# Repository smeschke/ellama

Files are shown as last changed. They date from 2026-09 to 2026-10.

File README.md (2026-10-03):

# eLlama

A four-wheel-drive outdoor robot base, walking-speed, that you drive with a handheld controller and that doubles as a mount for teleoperated or autonomous compute. You bring the battery and, if you want one, the computer.

Demo video: **[youtu.be/O5k8u-hmhis](https://youtu.be/O5k8u-hmhis)**. Try the 3D drive simulator without installing anything, hosted on Hugging Face Spaces: **[huggingface.co/spaces/r5d2/ellama-simulator](https://huggingface.co/spaces/r5d2/ellama-simulator)**.

## Who it's for

People who know they will want a capable outdoor robot in three to five years, and want something to iterate on now, before they buy the real one. Software, sensing, and autonomy ideas get tested on a robot that is cheap, repairable, and driven outdoors for real, so the ideas are proven by the time the commercial platform is worth buying.

The design leans on that. eLlama supplies only the slow-moving parts (motors, gearboxes, wheels, plywood, an ESP32, and a radio protocol) and leaves the fast-moving part, the computer, camera, and model, to the owner, in a box sized to take whatever comes next. The reasoning is in [`context-pack/01-overview.md`](context-pack/01-overview.md).

## Specs

| | |
| --- | --- |
| Drive | 4 x RS550 brushed motors, 100:1 gearboxes, 10 in pneumatic wheels |
| Power | Bring your own battery: 12 V 7 Ah SLA, 18 V cordless-tool pack, or 12 V LiFePO4 (see [`context-pack/05-battery-options.md`](context-pack/05-battery-options.md); LiFePO4 not yet tested) |
| Motor drivers | 4 x BTS7960 |
| Control | ESP32 (Llama Motor Board), ESP-NOW handheld controller or USB serial bridge to a computer |
| Sensing | AS5600 wheel encoders, IMU (GY-521 / MPU-6050 / ICM-20948 sketches) |
| Charging | Off the robot, with your battery's own charger |
| Weight | About 32 lb without a battery, 37 lb with one 12 V SLA, 42 lb with two |

## How it works

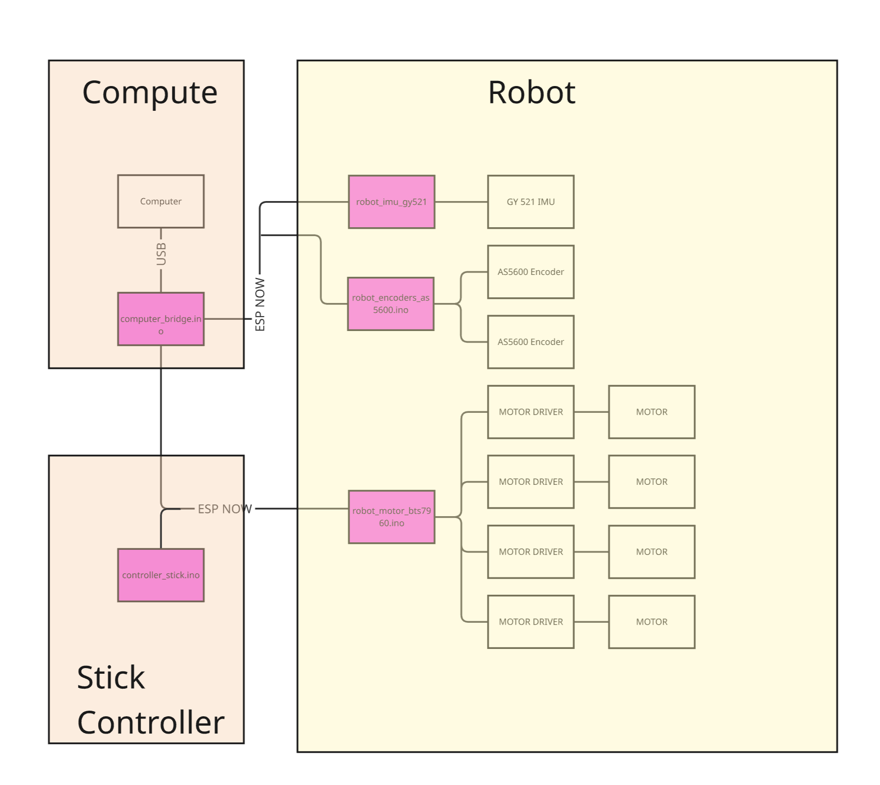
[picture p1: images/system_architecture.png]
System architecture


Drive the robot with the stick controller or with a computer through the USB bridge, one at a time, with no firmware changes. Both send the same drive packets over ESP-NOW to the motor board. The encoder and IMU boards broadcast telemetry that the bridge relays back to the computer.

## Status

**Works:** manual and remote driving, encoder and IMU telemetry, encoder-closed-loop moves ("go forward 10 inches") from Python or an AI agent through the MCP server, camera and lidar streaming over the network, and the calibrated simulators. Over 13 miles of field runs are logged in [`context-pack/Testing.csv`](context-pack/Testing.csv), failures included.

**Not there yet:** obstacle sensing, and an emergency stop beyond the power switch. Until obstacle sensors exist, anything commanding the robot must follow [`DRIVING_POLICY.md`](DRIVING_POLICY.md).

## Repo layout

| Path | What's there |
| --- | --- |
| [`context-pack/`](context-pack/) | Design docs and the [user manual](<context-pack/eLlama User Manual.md>) |
| [`firmware/`](firmware/) | ESP32 Arduino sketches (controller, motor board, bridge) |
| [`teleop/`](teleop/) | Python client/server scripts for driving, video, and lidar over the network |
| [`calibration/`](calibration/) | Sensor validation and calibration tools that read the computer bridge: live encoder/IMU view and calibration |
| [`mcp_server/`](mcp_server/) | MCP server so an AI agent can drive the robot by encoder feedback ("go forward 10 inches") instead of guessing a duration |
| [`simulation/`](simulation/) | Calibrated 2D/3D drive-command simulators and a CSV replay script |
| [`images/`](images/) | Photos and diagrams |

## License

Released under the [MIT License](LICENSE).

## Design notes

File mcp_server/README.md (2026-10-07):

# MCP server

An MCP server that lets an AI agent drive eLlama by encoder feedback instead of by
guessing a duration — "go forward 10 inches" becomes a tool call that watches the wheel
encoders and stops itself at the target, rather than a fixed-time open-loop command.

Talks over the same USB-serial link as `calibration/live_view.py`:
[`firmware/computer_bridge/computer_bridge.ino`](../firmware/computer_bridge/computer_bridge.ino)
on a spare ESP32, plugged into whatever machine runs this server. Reuses
[`calibration/bridge.py`](../calibration/bridge.py) for serial I/O, line parsing, and the
distance/heading math — one place that logic lives, not two.

**Read [`../DRIVING_POLICY.md`](../DRIVING_POLICY.md) before using this.** The short
version, enforced in code by `robot_server.py`: every tool that can move the robot
requires `confirmed_safe=true`, which must only be set after asking the human operator
about that specific move, in the moment. This server has no obstacle sensors — only
wheel encoders and an IMU — so there is no way for it to verify the area is clear on its
own. If real proximity/vision sensing ever gets wired into this server, a sensor-verified
small bump could skip the ask; until then, ask every time, regardless of move size.
First-time-testing-a-new-motor and full-power moves require asking even after that.

## Setup

```
python3 -m venv --system-site-packages mcp_server/.venv
mcp_server/.venv/bin/pip install mcp
```

(`--system-site-packages` so it reuses the `pyserial` already installed for
`calibration/`, instead of a second copy.)

Plug in the bridge ESP32 (flashed with `computer_bridge.ino`) — usually `/dev/ttyUSB0`.
`robot_encoders_as5600` and a `robot_imu_*` sketch need to be running on the robot itself
for telemetry to flow; without them, every drive tool refuses to move (see "no live
encoder telemetry" below).

Register with an MCP client via `.mcp.json` (already set up at the repo root) or run
directly to sanity-check it starts:

```
mcp_server/.venv/bin/python mcp_server/robot_server.py
```

## Tools

| Tool | Moves the robot? | Needs `confirmed_safe`? |
| --- | --- | --- |
| `read_telemetry()` | No | — |
| `look(width=640)` | No | — |
| `zero_odometry()` | No | — |
| `stop()` | Commands zero PWM (active braking) | No — always safe |
| `listen()` | Stops and releases control to the stick controller | No — always safe |
| `connect(port=None)` | No | — |
| `start_recording(name=None, auto_photo=False)` | No | No |
| `add_marker(text)` | No | No |
| `take_photo(note="")` | No | No |
| `stop_recording()` | No | No |
| `drive_distance(distance_inches, direction, pwm, confirmed_safe)` | Yes | Yes |
| `turn_degrees(degrees, direction, pwm, confirmed_safe)` | Yes | Yes |
| `drive_arc(radius_inches, degrees, direction, pwm, confirmed_safe, max_wheel_pwm=125, travel="forward")` | Yes (curved; 360° = full circle; `travel="reverse"` backs up along the arc) | Yes |
| `jog(left_pwm, right_pwm, duration_s, confirmed_safe, require_telemetry=True)` | Yes (raw, time-based) | Yes |
| `line_view(width=640)` | No | — |
| `person_view()` | No | — (finds people in the live frame, returns bearing to each) |
| `turn_to_me(confirmed_safe, max_seconds=30, name=None, spin_speed_dps=18, lost_timeout_s=1)` | Yes (spins in place, holds until it ends; max_seconds / lost_timeout_s of 0 = never) | Yes — once per run; refuses to start if 0 or >1 people are in view (ask the operator) |
| `turn_to_me_set(max_seconds, lost_timeout_s, spin_speed_dps)` | No (adjusts an already-approved run) | — |
| `turn_to_me_status(wait_s=0)` | No | — |
| `start_line_follow(confirmed_safe, speed_pwm=58, max_seconds=90, name=None, show_on_phone=False)` | Yes (autonomous, until it ends) | Yes — once per run (`show_on_phone` also shows the overlay + motor panel on the phone; see `phone/README.md`) |
| `line_follow_status(wait_s=0)` | No | — |
| `lights(on=True, brightness, color, effect, speed, intensity)` | No (WLED strip at `ELLAMA_WLED_HOST`, default 192.168.0.57) | — |
| `list_light_effects()` | No | — |
| `lights_blink(blinks=2, phase_s=0.3, color="00ff00", brightness=127, restore=True, fade=True)` | No (on off on off on = 1.5 s by default, each phase fading) | — |
| `speak(text, speed=1.3, max_brightness=127)` | No (Piper TTS out of this computer's speakers, WLED strip animates a mouth; blocks until done. Env: `ELLAMA_PIPER`, `ELLAMA_PIPER_VOICE`) | — |

`look()` returns a photo from the phone camera on the robot (Android "IP Camera" or "IP
Webcam" app). The phone is found by scanning the local /24 for ports 8080/4444, or set
`ELLAMA_CAM_URL` (e.g. `https://192.168.0.54:4444`) to skip the scan. A snapshot takes
~5-8s. It is advisory vision only and does not replace `confirmed_safe`.

## Recording a stick-driven run

The server can log telemetry while you drive with the stick: it only transmits when a drive
tool is called, so the bridge stays listen-only. Ask the agent to `start_recording`, drive,
ask for markers and photos as you go, then `stop_recording`. Everything lands in
`recordings/<name>/`:

- `<name>.csv` — same columns as `calibration/live_view.py --csv` plus a trailing `note`
  column, so `python3 calibration/analyze_csv.py recordings/<name>/<name>.csv` works. Rows
  are `ENC` / `IMU` samples, plus `MARK` (from `add_marker`) and `PHOTO` (from `take_photo`)
  rows that carry the state at that moment and the text or photo filename in `note`.
- `photo_001.jpg`, ... — full-size phone-camera snapshots. The `PHOTO` row is stamped when the
  photo is requested; the snapshot itself arrives ~5-8 s later.

`start_recording(auto_photo=True)` photographs the robot by itself whenever it comes to rest
(wheels still ~0.7 s) after moving at least ~4 in of wheel travel or ~10° of yaw since the
last photo, plus one at the start. The `PHOTO` row is stamped when the robot stopped. The
snapshot takes ~5-8 s, so if the robot moves again before it arrives, a `MARK` row notes
"robot moved during capture" and that photo shouldn't be trusted for pose. Thresholds are
the `AUTO_PHOTO_*` constants in `robot_server.py`.

Only one program can hold the bridge's serial port, so `live_view.py` can't run at the same
time. Only one ESP32 may transmit drive commands at a time: keep the stick controller on for
this (nothing is sent to the robot) and don't call a drive tool while it drives.

`drive_distance` and `turn_degrees` are closed-loop: they stop themselves once the
target is confirmed reached, or after a generous timeout, whichever comes first.
`drive_distance` uses the wheel encoders; `turn_degrees` uses the IMU's gyro-integrated
yaw (see "Known unknowns" below for why). Both refuse to run without live telemetry from
the sensor they depend on, always stop-and-settle before starting (so a direction
reversal is never commanded without a stop in between), and cap how far a single call
can go (`MAX_SINGLE_MOVE_IN` / `MAX_SINGLE_TURN_DEG` in `robot_server.py`) — chain
further confirmed calls for more, checking `read_telemetry()` between them, per
`DRIVING_POLICY.md`'s stop-check-decide-move loop. `jog` is the odd one out: open-loop,
raw PWM, fixed duration, no target — for bench/commissioning tests, capped at
`MAX_JOG_DURATION_S`.

`drive_distance`, `turn_degrees`, `drive_arc` and `jog` take `warn_lights=True`: right before the motors start the WLED strip does the 1.5 s fading `lights_blink` pattern (on off on off on, then solid green at 50% while moving) and is restored when the move ends. Pass `warn_lights=False` to skip it. A strip that can't be reached never blocks a move.

## Known unknowns

- **Direction sign: verified 2026-09-27.** Robot on blocks, wheels free to spin,
  `drive_distance(distance_inches=12, direction="forward", pwm=50, ...)` — all four
  wheels visibly spun backwards. `FORWARD_PWM_SIGN` is now `-1` to correct for this.
  Re-verify the same way after any change to wiring, motor board firmware, or which
  physical wheel is "left" vs "right".
- **Wheel encoders overestimate in-place turns by ~2x — verified 2026-09-27.** Robot on
  the ground, four 90° turns left then four right, pwm=60: the encoder-differential
  estimate (`dr - dl` over `track_width_in`) reported ~92° per commanded 90° turn, but
  the robot visually rotated only ~47° each time (confirmed by eye) — wheel scrub during
  an in-place spin turns the wheels much more than the chassis actually rotates. The
  IMU's gyro-integrated yaw over those same turns averaged ~49° per turn, matching the
  ~47° observed. `turn_degrees` now uses IMU yaw as its stop condition and ground truth;
  the encoder number is still returned as `encoder_degrees_estimate`, explicitly labeled
  unreliable. This means `track_width_in` miscalibration was never the real problem for
  turns specifically (it may still matter for other uses of encoder heading, e.g.
  `calibration/live_view.py`'s own dead-reckoning, which doesn't have an IMU fallback).
  IMU yaw drift over a multi-minute session is a separate, smaller concern this hasn't
  characterized yet — fine for single turns a few seconds long, unverified for anything
  longer.
- **Gear ratio is overridden in memory, not in the file.** `calibration/config.json`
  still says `gear_ratio: 6.33`; `calibration/analyze_run.py` found the true ratio is
  `4.5` (confirmed by `calibration/30_inches.csv`, a real tape-measured run). This server
  uses `4.5` regardless of what the file says — `TRUE_GEAR_RATIO` in `robot_server.py` —
  left that way deliberately so it could be tested independently before touching the file.

## Safety net beyond the confirmation gate

- `firmware/computer_bridge/computer_bridge.ino` now falls back to listen-only if no
  serial line arrives for 500ms while transmitting, so a crashed/killed server process
  doesn't leave the robot driving forever.
- The server itself sends `stop` on normal exit, `SIGINT`/`SIGTERM`, and at the end of
  every `drive_distance`/`turn_degrees` call (`try`/`finally`), whether or not the target
  was reached.
- Neither of those is a substitute for the confirmation gate — they bound how long a
  *stuck* command runs, not whether a command should have been sent at all.

## Line following

`start_line_follow` runs a camera -> detect -> steer loop on its own thread (`line_vision.py`
finds the 3/4in tape, `line_follow.py` turns it into wheel commands, `camera_stream.py` shares
the phone's `/video/mjpeg` stream). One `confirmed_safe` covers the run. It stops by itself and
reports why: `finish_candidate` (something like the end strip; may be paint or glare), `end_of_tape` (line
vanished right after a cross strip), `lost` (no line for 0.5 s), `stale` (no camera
frame), `telemetry_stale`, `timeout`, or `stopped` (`stop()` / `listen()` abort it at any time). These are claims for the AI to check with
`line_follow_report`, not verdicts. It never searches for a lost line. Other drive tools refuse while it runs. The run is recorded
to `recordings/<name>/` (telemetry CSV, `video.mp4`, `video_times.csv`, `follow_log.csv`).
`line_follow_sim.py` is a closed-loop sanity check of the controller, not a prediction -- its
constants are fit from `tape_manual_run1/2` and need tuning on the real robot.

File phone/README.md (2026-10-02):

# Phone display and benchmarks

The robot's Android phone runs Termux (F-Droid build) with Python, so the computer can put
live pictures on its screen and run small experiments there.

## One-time setup on the phone (Termux)
`pkg install python openssh python-numpy python-pillow tur-repo python-onnxruntime termux-api`,
install the **Termux:API** Android app too, and authorize the computer's SSH key
(`~/.ssh/ellama_phone_ed25519.pub` -> `~/.ssh/authorized_keys` in Termux). Start `sshd`
(port 8022) after every Termux restart. The phone address is whatever the camera app shows
(was 192.168.0.54).

## Live display (used by `start_line_follow(show_on_phone=True)`)
1. Copy `display_server.py` and `show.html` to `~/ellama/` on the phone:
   `scp -i ~/.ssh/ellama_phone_ed25519 -P 8022 display_server.py show.html termux@<phone>:ellama/`
2. In Termux: `cd ~/ellama && python display_server.py &`  (serves port 8080; kill it with
   `pkill -f display_server` from a *separate* command, not from the same ssh command line).
3. On the phone: `termux-open-url http://127.0.0.1:8080/show.html` (or open that address in the
   browser). Opening the plain image file with `termux-open` fails ("unable to display shared
   content"); the browser page works.
4. From the computer: `phone/show.sh picture.jpg` shows any image; the MCP server posts live
   frames with a motor-command panel when a run is started with `show_on_phone=true`
   (mcp_server/phone_display.py). Override the address with `ELLAMA_PHONE_DISPLAY`.

The display server has no login: anyone on the Wi-Fi can replace the picture. It only ever
writes `show.jpg`.

## Detector benchmark
`bench.py` runs the pose model (ONNX, numpy + onnxruntime + Pillow only) on an image and
times it: ~97 ms/frame at 320x192 with 6 threads on the A13-class phone (~230 ms at 480x288).
Models live in `models/` (gitignored; re-export from yolo11n-pose with imgsz=[320,192]).
This phone has **no gyroscope or magnetometer** (accelerometer only), so yaw still comes from
the robot's own IMU.

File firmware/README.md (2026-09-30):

# Firmware ⚡

Arduino sketches for every ESP32 in the system — one for the controller, one for the robot's motor board, plus a bench test sender. All of it is plain Arduino with no libraries beyond `esp_now.h`. Everything talks ESP-NOW on channel 1, no encryption, packet type distinguished purely by length.

## Sketches

| Sketch | Flashes onto | Does |
|---|---|---|
| [`controller_stick/controller_stick.ino`](controller_stick/controller_stick.ino) | single stick controller | Reads the joystick, arcade-mixes it, streams `DrivePacket{left, right}` every 40 ms |
| [`robot_motor_bts7960/robot_motor_bts7960.ino`](robot_motor_bts7960/robot_motor_bts7960.ino) | Llama Motor Board | Ramps toward the commanded left/right PWM on four BTS7960 channels, with a 300 ms fail-safe stop |
| [`computer_bridge/computer_bridge.ino`](computer_bridge/computer_bridge.ino) | spare ESP32 on a bench/PC | Reads `<left> <right>` over serial and re-sends it as `DrivePacket` over ESP-NOW; also listens for `EncoderPacket`/`ImuPacket` telemetry and relays them to serial as `ENC <left> <right> <ms>` / `IMU <ax> <ay> <az> <gx> <gy> <gz> <ms>` — listen-only until it is sent a drive line (`listen` returns it to silent), so it can log alongside the stick controller — lets a computer drive the robot and capture wheel-encoder and IMU data directly |
| [`robot_encoders_as5600/robot_encoders_as5600.ino`](robot_encoders_as5600/robot_encoders_as5600.ino) | Llama Encoder Board (prototype on a breadboard) | Reads two AS5600 wheel encoders (one per I2C bus), broadcasts `EncoderPacket{left, right, ms}` (12 bytes) over ESP-NOW ~50x/sec |
| [`bench_motor_bts7960_test/bench_motor_bts7960_test.ino`](bench_motor_bts7960_test/bench_motor_bts7960_test.ino) | bench-test ESP32 wired to the BTS7960 drivers, USB-tethered | Runs one motor channel (`fl`/`bl`/`fr`/`br`) at a time from the Serial Monitor at a low, clamped PWM for a few seconds, with slow ramping and auto-stop — no ESP-NOW |
| [`bench_encoders_as5600_test/bench_encoders_as5600_test.ino`](bench_encoders_as5600_test/bench_encoders_as5600_test.ino) | bench-test ESP32, USB-tethered | Standalone dual-AS5600 sanity check (per-encoder magnet alignment, angle/RPM; left on GPIO 21/22, right on 18/19) with Serial-only output, no ESP-NOW |
| [`robot_imu_icm20945/robot_imu_icm20945.ino`](robot_imu_icm20945/robot_imu_icm20945.ino) | robot — IMU board | Reads a GY-ICM20945 V2 (bank-switched registers, WHO_AM_I 0xEA) over I2C, broadcasts the same 16-byte `ImuPacket{accel, gyro, ms}` over ESP-NOW ~50x/sec, gyro-bias-corrected at boot |
| [`robot_imu_mpu6050/robot_imu_mpu6050.ino`](robot_imu_mpu6050/robot_imu_mpu6050.ino) | robot — IMU board (temporary, bench-taped) | Reads a GY-521 (MPU6050) over I2C, broadcasts `ImuPacket{accel, gyro, ms}` over ESP-NOW ~50x/sec |
| [`robot_imu_gy521/robot_imu_gy521.ino`](robot_imu_gy521/robot_imu_gy521.ino) | robot — IMU board | Hardened GY-521 sender: auto-detects address 0x68/0x69, accepts clone WHO_AM_I values, enables the ~44 Hz DLPF, skips failed reads and re-inits on disconnect, retries bias calibration if moved. Same 16-byte `ImuPacket` — no bridge/PC changes |
| [`bench_imu_mpu6050_test/bench_imu_mpu6050_test.ino`](bench_imu_mpu6050_test/bench_imu_mpu6050_test.ino) | bench-test ESP32, USB-tethered | Standalone GY-521 sanity check (gyro bias calibration, pitch/roll/yaw) with Serial-only output, no ESP-NOW |
| [`bench_imu_icm20945_test/bench_imu_icm20945_test.ino`](bench_imu_icm20945_test/bench_imu_icm20945_test.ino) | bench-test ESP32, USB-tethered | Standalone GY-ICM20945 V2 sanity check (gyro bias calibration, pitch/roll/yaw) with Serial-only output, no ESP-NOW — the GY-521's replacement candidate |

## Setup

Standard ESP32 Arduino toolchain — install the ESP32 board package, pick your board, flash over USB. The controller flashes through the same USB-C port that powers it, no disassembly.

The single stick controller broadcasts, so it drives any `robot_motor_bts7960.ino` listening on the same WiFi channel — no MAC address configuration needed. `computer_bridge.ino` broadcasts the same way once it is sent a drive line, so it works when driving from a computer instead of the stick; until then it only listens, so it can log telemetry while you drive with the stick.

**Only one ESP32 should transmit drive commands at a time.** The motor board follows whichever `DrivePacket` arrives last, so two senders fight and neither works properly. Unplug the stick controller from its battery when driving from the computer bridge, and put the bridge in listen mode (send `listen`) or unplug it when driving with the stick.

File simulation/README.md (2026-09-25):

# Simulation

Path planning and dry-run simulators for eLlama's open-loop drive commands (`pwml pwmr time_ms`, the same three numbers the firmware's `DrivePacket{left, right}` and `computer_bridge.ino` expect). Two UIs, each with a "simple" and a "complex" version:

| Script | UI | Input |
| --- | --- | --- |
| [`simulator.py`](simulator.py) | OpenCV, top-down 2D | Free-text MDI box, one `pwml pwmr time_ms` line per command |
| [`simulator_complex.py`](simulator_complex.py) | OpenCV, top-down 2D | Editable MDI grid, plus click-to-add waypoints (turn-then-drive or arc mode) |
| [`simulator3d.html`](simulator3d.html) | Browser, 3D (three.js) | Same free-text MDI box as `simulator.py` |
| [`simulator3d_complex.html`](simulator3d_complex.html) | Browser, 3D (three.js) | Same grid + click-to-waypoint planning as `simulator_complex.py` |

Run a Python one with `python3 simulator_complex.py`; open an `.html` one directly in a browser, no server needed. You can also try the 3D simulator without installing anything, hosted on Hugging Face Spaces: **[huggingface.co/spaces/r5d2/ellama-simulator](https://huggingface.co/spaces/r5d2/ellama-simulator)**.

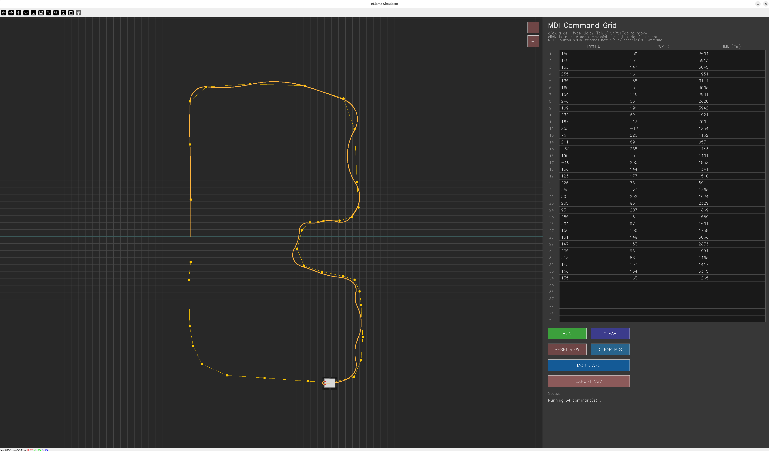
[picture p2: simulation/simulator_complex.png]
Top-down MDI grid simulator with a planned path

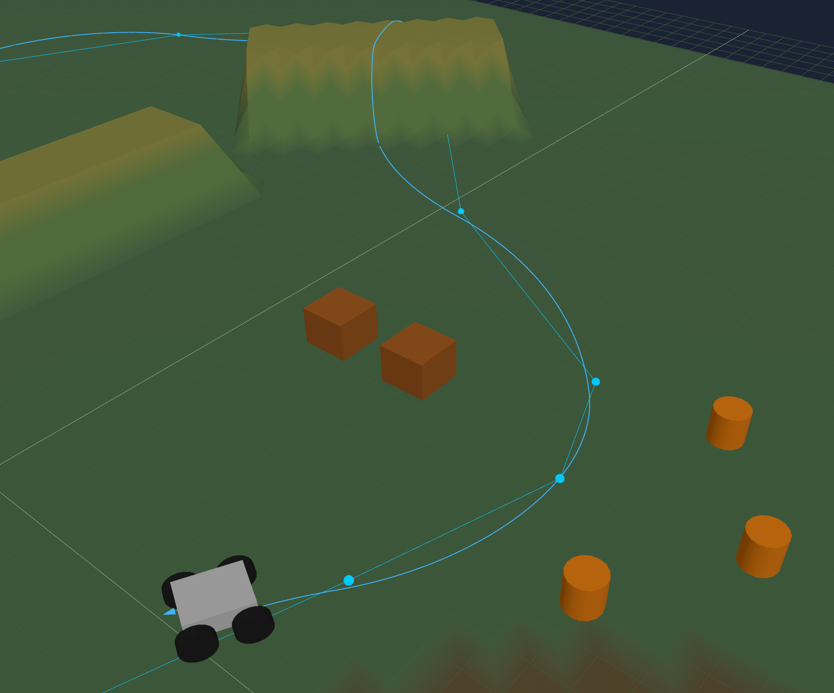
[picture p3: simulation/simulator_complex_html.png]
3D browser simulator with click-to-waypoint arc planning


## Why this is more than a toy

eLlama has no wheel encoders or other odometry feedback — commands are pure open-loop PWM + duration. To make the simulator worth trusting, I drove the real robot with simple commands (e.g. `120 -120 1800`), measured the actual distance/turn on the ground, and calibrated the simulator's speed and turn-rate model to match those measurements (see the `_SPEED_PTS` and `TURN_SCRUB_FACTOR` comments at the top of each script). The result: for a reasonable command like `150 150 2000`, the path drawn in the simulator tracks what the robot actually does closely enough to plan with.

Because there's no feedback, error still accumulates over a run, and it shows up most on turns (skid-steer scrubs unpredictably). Straight-line forward/back commands are the reliable case — under about 8 ft of travel, the robot usually lands within a fraction of an inch of the simulated endpoint. That's good enough to plan multi-step paths in the simulator, export them, and expect the real robot to follow along.

## Safety: MAX PWM is required, and there's no default on purpose

Every UI has a **MAX PWM** field. RUN and EXPORT CSV both refuse to act until it's set, and once it is, every command's `(pwml, pwmr)` pair is scaled down — preserving the ratio between them, so a turn's shape doesn't change, only its speed — so neither wheel exceeds it.

There's deliberately no baked-in default. The first version of this tool didn't have this control, and the click-to-waypoint arc planner (which picks whatever PWM gets to the clicked point at a steady speed) happily wrote out full-throttle 255 commands on tight turns — accurate to what the robot actually did, just much faster than expected the first time it ran unattended. That's a general risk, not specific to this planner: AI-assisted or auto-generated motion code tends to reach for whatever value produces the desired motion fastest, which in an unconstrained PWM range usually means near-maximum. **Start with the lowest PWM that's still effective for what you're testing, watch it run, and only raise the ceiling once you trust the path** — don't hand a fresh command list to the real robot at whatever PWM it happened to be written with.

Separately: PWM magnitudes much below ~40 tend not to produce any real motion at all — that's mechanical (motor/gearbox static friction), not a firmware-enforced deadband, so the simulator won't warn you about it. A command with `|pwm|` in the single or low double digits may look fine in the preview and simply do nothing on the real robot.

## Workflow

1. Build a path in the simulator — type commands directly, or click the ground to drop waypoints (complex versions plan the turn+drive or arc command for you).
2. Click **EXPORT CSV** (Python) or the export button (3D) to write `pwml,pwmr,time_ms` rows to `exported_path.csv`.
3. Replay it on the real robot with [`send_csv.py`](send_csv.py), which streams each row over serial to an ESP32 running `computer_bridge.ino` at the wire protocol described in [`firmware/README.md`](../firmware/README.md):

   ```
   python3 send_csv.py exported_path.csv --port /dev/ttyUSB0
   ```

   It always sends `stop` on exit, Ctrl+C, or error, since `computer_bridge.ino` repeats the last command forever until told otherwise.

## Robot model

Both simulators use the same kinematic model, built from the real chassis dimensions in [`images/chassis_dimensions_isometric.png`](../images/chassis_dimensions_isometric.png):

- Differential (skid-steer) drive: `v = (v_l + v_r) / 2`, `omega = (v_r - v_l) / effective_track_width`
- PWM → speed is piecewise-linear, calibrated from real straight-line runs
- Turning uses an inflated *effective* track width (`TURN_SCRUB_FACTOR`) to account for how much a 4-wheel skid-steer chassis scrubs sideways during a turn, calibrated from a real 90° pivot

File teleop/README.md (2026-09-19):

# Teleop

Python client/server pairs for driving eLlama, watching its camera, and viewing lidar sweeps over the network. Servers run on the robot's compute module (a Pi); clients run on your laptop.

## Scripts

| Script | Runs on | Does |
| --- | --- | --- |
| [`command_server.py`](command_server.py) | Pi | Receives drive commands (`FWD`, `REV`, `SPIN <nx>`, `STOP`) over TCP and forwards motion to the ESP-NOW sender over serial at 20 Hz |
| [`command_client.py`](command_client.py) | laptop | Connects to `command_server.py` and drives with the keyboard (w/s/a/d, up/down for speed, space to stop) |
| [`video_server.py`](video_server.py) | Pi | Captures the camera and streams JPEG frames over TCP |
| [`video_client.py`](video_client.py) | laptop | Connects to `video_server.py` and displays the live feed |
| [`lidar_server.py`](lidar_server.py) | Pi | Reads LD06 lidar packets over serial, accumulates one 360° sweep at a time, and streams each finished sweep over TCP |
| [`lidar_client.py`](lidar_client.py) | laptop | Connects to `lidar_server.py` and displays each completed sweep |

Each pair is independent — run whichever combination you need (e.g. `command_server.py` + `video_server.py` together for full teleop, or just the lidar pair on its own).

Servers listen on plain TCP with no encryption or auth, matching the firmware's ESP-NOW link — see [`firmware/README.md`](../firmware/README.md).

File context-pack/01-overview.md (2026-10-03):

# 01 — Overview

## What it is

eLlama is a four-wheel-drive outdoor robot base, roughly the size of a large dog, that a
person can lift into a car trunk. It ships as a base: chassis, four driven wheels, the
motor board, and a handheld controller. Add a battery, switch it on, and drive it with no
computer and no software.

It is also a mount for compute. A box on the front deck takes a single-board computer and
whatever sensors the job needs — a camera, a lidar, an IMU. With that fitted, the same
chassis is a teleoperated or autonomous platform. The robot ships with an empty box
intended for a single board computer or mini pc.

Two things are bring-your-own: the **battery** and the **compute**. You choose both. The
battery choices are in `05-battery-options.md`.

Both of those are true at once, and the relationship between them is the product.

## Why obsolescence is the real problem

A robot sold with a specific SBC in 2026 is carrying a 2026 decision forever.

eLlama supplies only the slow-moving parts: motors, gearboxes, wheels, plywood, an ESP32,
and a radio protocol. None of those will be meaningfully better in three years. The
fast-moving parts — the computer, the camera, the model running on it, and the battery
chemistry that is cheapest this year — are the owner's, replaced on the owner's schedule.
The compute goes in a box sized to accept whatever comes next, and the battery is one
the owner already has or can buy locally.

That is also why the mechanical design targets ubiquitous parts
(`03-drivetrain-power.md`). A ride-on-toy gearmotor and a hand-truck tire will be
available and cheap for decades.

## Who it is for

**Someone who already has the computer.** A student with a Jetson, a hobbyist with a Pi
and a lidar, a researcher who needs a body for an algorithm. They do not need a robot;
they need something to put the robot brain into that will survive a curb and a lawn.

**Someone who wants a task done outdoors.** Hauling, patrol with a light, inspection with
a camera, a repeatable route past fixed points. The chassis does the moving; the
task-specific part is bolted on.

The overlap between those two — a platform that earns its keep between experiments — is
the interesting position. A research platform costs money while it sits. This one hauls
the trash, which means it gets driven daily, which means real field time and real
failures instead of staged demos.

## Why wheels, and why this size

Legs are an evolutionary answer to a constraint biology has and robots do not: you cannot
run blood and nerves through a continuously rotating joint, so nothing that evolved ever
grew a wheel. We can. And humans have spent centuries flattening the ground for wheels —
driveways, paths, sidewalks, shop floors. A wheeled robot inherits all of that for a
fraction of the cost and failure modes of a leg.

The size is set by two opposing limits, covered in detail in `02-physical-design.md`:
small and light enough that a stranger can shove it out of the way and one person can
lift it into a compact car, large enough to cross grass, gravel, and a curb with a load.
Indoor-scale robots fail the second test. Mowers, UTVs, and quadrupeds fail the first,
and are priced to match.

## What it is not

Not industrial-tough. Not weatherproofed for permanent outdoor installation. Not a
certified safety product. Not a finished autonomy solution — there is no SLAM stack in
the box, and no ROS (`04-control-architecture.md` explains why).

It is a platform built to be learned on, modified, and re-revved, made from parts you can
replace at a hardware store.

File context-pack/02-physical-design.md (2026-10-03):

# 02 — Physical Design

## The two limits that set the size

Everything about the footprint comes from a pair of opposing constraints:

**Upper bound — one person, one lift, one trunk.** The robot has to go in the back of a
compact car without a ramp, a second person, or a decision about whether this is a good
idea. That caps weight in the mid-30s of pounds and the footprint at something a person
can get their arms around.

**Lower bound — real ground.** It has to cross grass, gravel, a sidewalk lip, and a
slope, carrying something. That sets a minimum wheel diameter and a minimum track width
before it becomes a toy.

Most mobile robots fail one of these. Indoor platforms clear the first and fail the
second — clean odometry on a flat floor hides every hard problem. Mowers, UTVs, and
quadrupeds clear the second and fail the first, being heavy or fast enough that you do
not want a stranger standing next to one.

## Weight, and why you bring the battery

At **~32 lb dry / ~37 lb with one 12 V 7 Ah SLA battery**, this is a real one-person lift
with a handle. At 42 lb with two SLA batteries it is at the edge of comfortable. A tool
pack or a LiFePO4 battery weighs less than an SLA, so those builds come out lighter.

The battery is bring-your-own, for the same reason the compute is. It solves three
problems at once:

1. **Shipping classification.** Sealed lead-acid falls under UN2800 and lithium batteries
   under their own dangerous-goods classes, each with marking requirements, carrier
   restrictions and surcharges. Not shipping a battery removes that entire category of
   work from fulfilment.
2. **Carton weight.** The shipped box stays under 40 lb.
3. **Choice.** Most buyers already own a battery that works, usually a cordless-tool pack.
   There are three supported options (`05-battery-options.md`), with current prices in
   `battery_bom.csv`.

## Geometry: 17 wide × 16 long

**This is the single best design detail in the robot, and it cost one inch of plywood.**

The wheels are one inch further apart than they are front-to-back — 17 in track, 16 in
wheelbase, a ratio of 0.94.

A four-wheel skid-steer robot has no steering. To turn, all four tires must scrub
sideways against the ground. Wider skid-steer platforms need less differential thrust
than longer ones.

It is also the cheapest possible fix. It is not a mechanism, a differential, or a control
strategy. It is where you put the axle holes.

## Four wheels, not two

**The original prototype was two driven wheels plus a caster. It tipped over, and it was
miserable.** That is the largest design iteration in the project's history. On one tip it
broke the Raspberry Pi 4 riding on the deck — the instability was not a hypothetical
failure mode, it took out real hardware, and it is the direct reason the design moved to
four driven wheels. No footage of the tip exists; it predates the project's habit of
filming test runs.

A two-wheel-plus-caster robot is statically stable only over the triangle formed by its
three contact points, and the caster end of that triangle moves as the caster swivels.
Accelerate, brake, or hit a rock and the effective support polygon shrinks exactly when
you need it. Outdoors on uneven ground the failure is frequent, and every occurrence
risks whatever is bolted to the deck — which, for the intended use, is someone's camera
or lidar.

Four driven wheels give a fixed rectangular support polygon that does not change with
steering, and four contact patches for traction on loose surfaces.

## The compute module

The compute module bolts onto the chassis. It holds whatever compute and sensors the owner prefers — a Raspberry Pi, a camera, a
lidar, an IMU, a GPS, or something else entirely. Internal volume is 10 W × 4 D × 10 in H.

### Sensors live in the module, not on the chassis

An IMU is the clearest case. Anything that *measures*
belongs next to the thing that *decides*, and deciding is the owner's half of the system.

So the chassis carries no sensors at all, and the module is where an IMU, a camera, a
lidar, or a GPS goes. The one thing that would ever argue for putting an IMU back on the
robot is tip detection — a chassis-level safety behaviour that cannot depend on a module
which may not be fitted. That is not built, and it is not planned.

### A roll cage as well

It is also a small roll cage. A platform meant for outdoor experimentation *will* end up
on its side, and the thing that breaks should not be the owner's lidar.

The module is optional. With the handheld controller the robot needs neither the module,
the compute, nor the lidar — and a laptop or a phone can stand in for the module
entirely.

## Materials

**¾ in hardwood plywood deck, table-saw cut.** Plywood is stiff, cheap, dimensionally
forgiving, takes a screw anywhere, and can be re-cut by the owner with tools they already
have. It is repairable with a jigsaw rather than a purchase order.

**3D-printed mounts, adapters, and body shell.** Motor mounts, hub adapters, axle blocks,
battery holder, motor driver mount, and body — all intended to be reprinted and
modified, and the body shell in particular is meant to be reshaped by the owner.

**½ in allthread axles in plywood capture blocks.** Cheap, straight enough, available
everywhere, and replaceable at any hardware store on a Sunday.

## Clearance and carrying

**4 in of ground clearance** under 10 in wheels puts the deck underside just below the
axle line. That is the right relationship: the tires decide what the robot can climb, not
the belly. A platform with big wheels and a low pan grounds out on exactly the obstacles
the wheels were chosen to clear, and this one does not.

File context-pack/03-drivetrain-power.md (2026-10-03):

# 03 — Drivetrain and Power

## The ride-on-toy drivetrain

Four RS550 brushed DC motors with 100:1 triple-spur gearboxes — the drivetrain out of a
children's ride-on car.

This is the highest-leverage sourcing decision in the project. That market has already
solved the exact problem: move roughly 100 lb at walking speed on 12 V, cheaply, reliably
enough for a product sold to parents, at a volume that makes the part permanently
available. The gearmotor costs about $8.

Consequences worth naming:

- **Torque is not a constraint.** The grade ceiling is a question about tires and
  surfaces, not motors. This is also why it will tow an adult — demonstrated so far as a
  proof of concept (a person in a wagon, towed behind the robot), not a rated capability.
  Towing an actual trailer is a stated future goal, not a current one.
- **The gear ratio sets the speed correctly with no second stage.** 100:1 on a 10 in
  wheel lands at walking pace. No additional reduction, no belt, no chain.
- **Availability outlives the product.** These are stocked by dozens of sellers and are
  not going away.
- **The speed figures come from testing.** On a 12 V SLA battery the robot moves at about
  1 m/s.

**The cost is backlash.** Triple spur reduction in a toy-grade housing has meaningful
play. It is fine for open-loop hauling and teleoperation, and it is the first thing that
will hurt closed-loop odometry. It is the single biggest known weakness of the
drivetrain.

## Brushed, not brushless

Brushed DC at this price point is simply easier: two wires, direction by polarity, speed
by PWM, no commutation, no encoder required, no controller firmware to get wrong. It
fails gracefully and predictably, and anyone can diagnose it with a battery and two
clips.

Brushless would be more efficient and quieter, but it requires an ESC per motor, sensored
or sensorless commutation, and a materially harder debugging story for a platform whose
buyers are learning.

## Why 10 inch pneumatic wheels

Six reasons converge on this one part, which is why it is worth stating fully rather than
as "handles sidewalks."

1. **Obstacle clearance.** A 5 in radius rolls over a sidewalk lip, a root, a curb cut,
   or a rock without a run-up. Small hard casters stop dead at exactly the features that
   are everywhere outdoors.
2. **The air is the suspension.** A low-pressure pneumatic tire absorbs impact and
   conforms to uneven ground. This removes suspension from the design entirely — no
   springs, no pivots, no articulated axles, no extra failure modes.
3. **Ubiquity and price.** 10 × 3.50-4 is the hand-truck and wheelbarrow size, stocked at
   every hardware store on Earth for about $7.
4. **The bore is a standard.** A 5/8 in bearing bore takes ½ in allthread with an
   off-the-shelf bushing — an axle assembly from the plumbing and fastener aisles.
5. **Contact patch on turf.** A wide, low-pressure patch crosses grass without tearing it
   and floats on loose gravel instead of digging in.
6. **Diameter sets the gear ratio.** A 10 in wheel with a single 100:1 stage lands on
   walking speed. A smaller wheel would need a second reduction stage.

Point 5 interacts with skid steering in a way worth understanding: a larger contact patch
means more scrub resistance in a turn. That cost is what the 17 × 16 geometry in
`02-physical-design.md` buys back.

## Speed

Measured working speed is **1.72 mph average over 460 logged minutes**, with the fastest
logged run at 2.87 mph.

## Power

**Bring your own battery. Three options are supported:** a 12 V 7 Ah sealed lead-acid
battery (one, or two in parallel), an 18 V cordless-tool pack, or a 12 V LiFePO4 battery.
The full comparison and the rules that apply to all of them are in
`05-battery-options.md`; current prices are in `battery_bom.csv`.

How each one behaves on this drivetrain:

- **12 V SLA.** The baseline. The motors are 12 V ride-on-toy motors, and the speed and
  PWM figures in this repo were measured on it. About 4.85 lb each. Runtime is roughly
  1.5 hours per battery at working duty — an inference from logged voltage drop, not a
  measurement. A second battery adds capacity, not voltage.
- **18 V tool pack.** Tested with one Milwaukee M18 2 Ah pack. It worked well and was
  faster than two SLA batteries. The firmware sends duty cycle, not speed, so the same
  command runs the motors at a higher voltage. Re-run the speed calibration before trusting
  the SLA numbers.
- **12 V LiFePO4.** Not tested yet. At 12.8 V nominal it should match SLA, but check the
  BMS discharge rating first.

The battery is bring-your-own because it is a fast-moving part, the same argument as the
compute (`01-overview.md`). The robot has no charging circuit and no dock: you charge the
battery off the robot with its own charger.

## Accessory power

The compute module has an inline-fused barrel jack that carries **battery voltage,
unregulated**. That is about 12 V on SLA or LiFePO4 and roughly 16–21 V on a tool pack.
Whatever you mount in the bay must accept that range, or sit behind its own converter.

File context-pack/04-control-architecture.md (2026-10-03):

# 04 — Control Architecture

## The interface is two numbers

The chassis accepts a left speed and a right speed. That is the entire contract.

Everything above that line is replaceable and everything below it is fixed. The
drivetrain, wiring, and motor firmware never change, regardless of what produces the
numbers. There is no SDK and no middleware to learn.

This is what makes manual and autonomous the same robot. They are not modes — they are
different senders. Switching between them is unplugging one command source and plugging
in another, and the motor board cannot tell the difference.

## Two ways to send them

**Handheld controller** — a single analog stick, talking directly to the motor board over
ESP-NOW. No computer involved. This is what ships working.

**Onboard compute** — a program on the Pi writes left/right values over serial to an
ESP32 acting as a radio bridge. The Pi can be connected to the internet for
teleoperation.

One constraint: only one sender may transmit at a time. Commands do not work properly when
two different ESP32s are sending them, because the motor board follows whichever packet
arrives last. When using the computer bridge, unplug the stick controller from its battery;
when using the stick controller, put the bridge in listen mode (or unplug it).

The handheld path needs none of the others to exist. That ordering matters: the robot is
complete without compute, and compute is an expansion rather than a dependency.

Onboard compute doesn't have to be onboard, either: a desktop running the simulator and an
ESP32 running the same `computer_bridge.ino` is the same sender, just relocated off the chassis
entirely (`07-simulation.md`).

## One controller drives every robot — on purpose

The controller does not pair to a robot. It broadcasts, and any motor board listening on
the channel drives from it — no bind procedure, no MAC address to enter, no per-unit
configuration at the factory or by the owner.

That sounds like a limitation — "the controller can't be exclusive to one robot" — until
you notice what it buys: a controller and a robot that have never seen each other work
together the moment both are powered on. That is what "ships working" actually rests on.
There is no pairing step to document, no pairing step to get wrong, no pairing step to
walk a customer through over email when it fails.

It also means the same controller scales up instead of down. Someone with more than one
robot does not need a second controller or a rebind ritual to switch between them — one
controller drives whichever robot is in front of them. For anyone herding a small fleet,
that is the same broadcast behavior read as a feature rather than a workaround.

This is the other side of the tradeoff already stated above: the link has no
authentication because authentication is what would turn "any controller drives any
robot" back into "one controller, one robot, and a pairing step in between."

## Stock firmware is a starting point, not a ceiling

Everything above describes what ships: broadcast, unencrypted, unauthenticated, ESP-NOW on a fixed channel. That is a deliberate default, not the only supported mode. It is intended that owners experiment with it and change it.

The firmware is plain Arduino with no framework to fight, so the modifications this invites are direct:

Unicast instead of broadcast — address the packet to one robot's MAC and get exclusivity back, for someone who wants "my controller, my robot" instead of the out-of-the-box fleet behavior.

Encryption and authentication — ESP-NOW supports encrypted peers; adding that trades the zero-setup default for a link that can't be casually driven by a stranger, for anyone whose use case makes that tradeoff worth it (see the tradeoff already named above).

Deliberate delay or offset — staggering when a robot acts on a broadcast packet, or filtering which packets it responds to, is what turns "every robot obeys every controller instantly" into controlled herding of a group, rather than all of them doing the same thing in lockstep.

Or whatever the owner's own use case actually needs — the point is not this specific list, it's that the stock configuration is a known-good starting state, not a locked one.

This is the same argument as the split in 01-overview.md between the base and the owner's compute and battery, one level down: the platform ships with one deliberate, working default so it's usable immediately, and leaves the protocol itself as open territory for the owner to shape, the same way the compute bay leaves the brain open.

## Why a direct radio link rather than WiFi

The controller link is connectionless: no access point to join, no DHCP, no pairing
ritual, no reconnect storm when the robot drives behind a shed. For a machine that works
in a field with no infrastructure, *the absence of a network to join* is the feature.

Network teleop layers TCP on top only when a Pi is fitted and a network exists — and even
then the last hop to the motors is still the direct radio link.

**One deliberate tradeoff, stated plainly:** the link is unencrypted and unauthenticated.
Anyone in radio range with the right hardware can drive the robot. That is acceptable for
a hobby platform at walking speed that a person can physically stop; it is not acceptable
for anything unattended or valuable. A bounded decision, not an oversight.

## Layered failsafes

If the motor board receives no signal from the controller for a fraction of a second, it enters
failsafe and commands PWM zero.

PWM zero is not neutral: the BTS7960 drivers hold both terminals of each motor near
ground rather than letting them float, shorting the motor's back-EMF through the driver.
That is active (dynamic) braking, confirmed by testing — not just the 100:1 gear
reduction holding the robot on a slope, though that helps too.

*(Specific timeout values live in the firmware.)*

## Wiring is standardized

The custom PCB is what makes every robot wire up identically. It is documented well
enough that a user can reflash the motor board and change behaviour without tracing a harness
first.

The ESP32 DevKit is socketed and hand-populated onto the board rather than reflowed as a
bare module (`06-manufacturing-cost.md`), which keeps its USB-C port exposed at the edge
of the board. That single port is what makes the three control paths above physically
possible on the same hardware: flash new firmware over it, or plug it into a bench PC and
drive the robot directly with `computer_bridge.ino` — the same port, no case to open, no
programmer to attach.

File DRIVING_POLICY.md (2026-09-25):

# Driving Policy

Rules for anyone or anything sending drive commands to eLlama's real
motors — a human at a joystick or teleop client, or an AI testing firmware,
running a script, or sending raw `<left> <right>` values over
`computer_bridge.ino`. This is not a design-rationale document like
`context-pack/`; it's a set of constraints for actually operating the robot.

Most of what's written here is how a human already drives this robot by
instinct — ease up from zero, watch what happens, stop before changing your
mind about direction. It's written down because AI operators have
repeatedly done the opposite: picking PWM values that look "clearly
visible" for a demo instead of conservative, jumping straight to a target
instead of testing upward from nothing, reversing direction without
stopping first, and chaining moves together assuming they'll blend cleanly.
An AI operating this robot should follow every rule here exactly, even when
a task seems to justify skipping one. A human operator will likely recognize
most of it as what they already do.

## 1. Get permission before anything moves

Before an AI operator sends any command with a nonzero left or right value
to real hardware:

1. Confirm the robot is physically safe to move — clear area, no people or
   pets nearby, not balanced somewhere it could fall.
2. State the exact command about to be sent, and wait for the go-ahead.

This does not apply to read-only or zero-motion actions: reading encoder
telemetry, checking serial connectivity, or sending `stop`. It applies to
every command with a nonzero PWM, even a small one, even a "quick test,"
even if the request was phrased as a general question rather than an
explicit instruction to move the robot. (A human driving directly is
already the one making this judgment in real time — this rule exists for
the case where the thing sending commands isn't the thing watching the
robot.)

## 2. This is not a simulation — there is no reset

In a simulator, a bad command just means you re-run it. On the real robot,
a bad command can flip it, drive it into something, or drop it off a curb —
and there is no undo. If it flips and the Pi breaks on impact, there is no
"try again," there is a robot that no longer has onboard compute. Every
command is one-shot and consequential, not an iteration you get to throw
away if it doesn't work.

The practical effect: treat every real-world command with the caution
you'd give an action you can only take once, because that's what it is. If
a plan only works out when several things go right in a row, that plan is
wrong for real hardware, even if it would be fine in
`simulation/`.

## 3. Start at the lowest PWM that might work, not a value that will obviously work

When you don't already know the right PWM for a task, the first command is
not a best guess at what will produce a clean result — it's the smallest
value with a chance of producing *any* visible result. Then evaluate and
adjust:

1. Send the low value.
2. Observe: did it move at all? Which direction? Was that the expected
   result?
3. If it didn't move enough, increase and try again.
4. If it overshot, something may already be stressed or damaged — there is
   no equivalent "step down and retry" once metal has moved.

This asymmetry is the whole reason to be conservative: undershooting costs a
few seconds of iteration. Overshooting risks the gearbox, the wheels, or
whatever the robot just ran into. Never pick a value because it will make
the result unambiguous to observe — a convincing demo is not the goal, and
"clearly visible" is exactly the reasoning that has produced bad commands
before.

**Concrete numbers for this robot — sourced, not guessed:**

- **Ramp rate:** `robot_motor_bts7960.ino` moves the commanded PWM by at most 1
  count per 3 ms toward its target
  (`RAMP_STEP`/`RAMP_DT_MS`,
  [`firmware/robot_motor_bts7960/robot_motor_bts7960.ino:32-33`](firmware/robot_motor_bts7960/robot_motor_bts7960.ino#L32-L33))
  — about 333 PWM/s, or ~0.77 s to go from 0 to full 255.
- **Manual/teleop operating ceiling:** 128/255, chosen after top speed was
  found too fast
  (`SPEED_MAX`,
  [`teleop/command_client.py:37`](teleop/command_client.py#L37)).
- **Scripted ground-truth-run ceiling:** 125/255, used for calibration and
  encoder-verification runs where the robot actually rolls
  (`MAX_PWM_CEILING`,
  [`firmware/computer_bridge/toandfro.py:29`](firmware/computer_bridge/toandfro.py#L29)).
- **Absolute hard limit:** 255/255 is the most the wire format can express
  (`DrivePacket.left`/`.right`, range -255..255,
  [`firmware/robot_motor_bts7960/robot_motor_bts7960.ino:37-40`](firmware/robot_motor_bts7960/robot_motor_bts7960.ino#L37-L40)).
  This is a format ceiling, not a safe value — it says what the hardware
  *can* be told, never what it *should* be told.
- **First command on a setup you haven't personally verified:** there is no
  code constant for this — it's a floor this document sets, not a fact
  read from a file. Start at 5–10% duty (13–26/255) regardless of any
  script's own default, then work upward per the loop above.

These are ceilings, not targets — start below them and work up. If the
code changes, the file is right and this document is stale: check the
actual constant before trusting a number written here.

## 4. Ramp, don't jump — and never skip through a reversal

Never command a large instantaneous change in PWM, in either direction:

- No 0 → high jumps. Ease up in steps; even a coarse few-second ramp is
  enough. This is both mechanical (the drivetrain is a 100:1 triple-spur
  gearbox off a ride-on-toy chassis — sudden torque is exactly what shears
  gear teeth) and social (easing a joystick forward gives anyone nearby a
  couple of seconds to notice the robot is about to move and get clear; a
  sudden jump doesn't).
- No sign reversals without a stop in between. Going from `+100` to `-150`
  in one step is worse than either value alone — it reverses load on the
  gear train at full magnitude instantly. Always command `0` (or let it
  reach zero) before commanding the opposite sign.
- Braking is not exempt. Sudden PWM-to-zero is a hard stop, not a neutral
  action — `robot_motor_bts7960.ino` drives both motor terminals near ground at
  PWM 0, which is active dynamic braking through the BTS7960 drivers, not
  coasting. Treat a stop command with the same "don't do it abruptly at
  high speed" caution as a throttle command.

Note: `robot_motor_bts7960.ino` already ramps toward whatever target it receives
(`RAMP_STEP`/`RAMP_DT_MS`), and has a fail-safe zero on signal loss
(`CMD_TIMEOUT_MS`). That is a mechanical safety net, not a substitute for
choosing sane targets — it limits *how fast* a bad command gets applied, it
doesn't make a bad command a good one. Don't rely on it to excuse picking a
value you wouldn't otherwise choose.

## 5. You can string commands together — but chaining needs more sensing, not less

Stopping fully between every single command isn't a hard requirement. What
matters is that each command is issued with an accurate picture of where
the robot actually is and what it's actually doing — and stopping to check
is simply the easiest way to guarantee that when you don't have another way
to know.

If you chain moves without stopping, you're acting on your *prediction* of
where the robot will be when the next command starts, not a measurement.
That's fine as long as something is actively confirming the prediction as
you go — encoder counts, lidar, a camera, a timeout with a sane fallback —
so a sequence that's drifting off-plan gets caught and corrected instead of
compounding silently until something is already wrong. Chaining fixed-
duration, open-loop moves with no feedback in between is how a small error
in step one becomes a bigger one by step three.

Default to the stop → check → decide → move loop for anything without solid
live feedback, which today is most of this robot's scripts (`toandfro.py`
and friends drive at fixed PWM for a computed duration or until an encoder
threshold, not with continuous position tracking). Example: aligning the
robot square and centered in a doorway isn't done by computing the right
trajectory and driving it in one motion — it's driving up, stopping,
backing off, stopping, checking the alignment, and driving up again,
correcting a little each pass. That works because every pass ends with a
clean, motionless read of position. A continuous "smart" approach doesn't
give you that read while the robot is still moving and carrying momentum
from what you just told it to do — so without sensing good enough to
replace the stop-and-look step, don't skip it.

## 6. Why this reads differently from how AI defaults to operating

Left to its own judgment, AI tends to pick the PWM value that most cleanly
demonstrates the intended behavior, apply it immediately at full target
magnitude, treat reversing direction as just a sign flip, and chain moves
together the way you'd chain function calls — assuming each one starts
clean and composes predictably, the way it would in a simulation. All of
that is wrong for a physical drivetrain with inertia, backlash, gear teeth
that don't forgive a shock load, and no undo if something goes wrong. A
human who has actually held the joystick does none of this — they ease up
from zero, watch what happens, let it settle or actively confirm it's on
track, and never expect the first input to be the last one they need.
That's the standard this document is asking an AI operator to hold itself
to — and, hopefully, a description a human operator already recognizes as
just how you drive the thing.

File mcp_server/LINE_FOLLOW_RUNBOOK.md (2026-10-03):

# Line-follow runbook: what to do when the script stops

The follower (`start_line_follow`) is a simple rule-based script on purpose. It is good at
steady tracking and bad at judgment calls (paint chips, glare, scratches, shadows). So the
design is: **the script drives; when it stops, the AI looks at the images and decides.**
A script status is a *claim*, not a verdict -- that includes `finish_candidate`.

## The procedure (every stop, no exceptions)

1. **Look first.** Call `line_follow_report`. View the contact sheet and the fresh still
   before reasoning about logs or code. If the overlay is ambiguous, take a raw `look()`
   (the camera is mounted sideways: the robot's front is on the right of that photo).
2. **Give a verdict**, in the user's terms: what the script said, and what the images show.
3. **Pick the recovery** from the table below.
4. **Authority.** Suggest the move and wait for a go-ahead, unless the user has said
   **FULL AUTO** (all caps). Under FULL AUTO, do it, then tell the user what you did.
   Even under FULL AUTO, stop and ask after 3 recoveries in a row without progress, and
   for anything that is not a small nudge/restart.
5. **Restart** with `start_line_follow` (needs `confirmed_safe`; the line must be in view
   with >= 3 bands).

Don't jump to changing code. Most stops are a nudge and a restart.

## Verdicts and recoveries

| Script says | Check in the images | Verdict | Recovery |
|---|---|---|---|
| `finish_candidate` | Is there a real perpendicular strip across the whole line, or glare/paint/a scratch? Compare the annotated and RAW images. | Real finish, or false finish | Real: done, tell the user. False: restart with `ignore_finish_s` (about 6-8) |
| `end_of_tape` | The line vanished right after a cross strip was in view. Is a T/crossbar going under the camera in the frames, and bare floor after? | Real end of course (usually) | Confirm with a raw `look()`; if the floor ahead is bare, it's done. If tape continues, nudge toward it and restart |
| `stale` | Is the line still in view and the robot where it should be? Do the last log rows repeat identically? | Stalled on the line (spin below the wheels' breakaway effort) or a late camera frame | Nudge toward the line (`turn_degrees` ~10 deg, pwm 70), restart |
| `lost` | Which side did the line leave on (`last_line_seen.side`)? Is it visible in the still? | Off the line, left or right | Turn toward that side by the angle the still suggests, restart |
| `telemetry_stale` | Is the board link alive (`read_telemetry`)? | Link problem | Reconnect (`connect`); don't drive until telemetry is live |
| `timeout` | Where is the robot now, and is it making progress? | Slow or very long course | Restart if it's on the line |
| `stopped` | Someone called `stop()`/`listen()` | Operator stop | Do nothing; ask the user |

Nudge sizes that worked: right 10-20 deg for a mid-curve stall (it came out at 11-21 deg
by IMU).

## Known quirks (as of 2026-10-03)

- **The follower does not need the encoders.** Its start gate and watchdog use the IMU
  stream. A dead encoder (right encoder's magnet fell off) doesn't block it. Other tools
  (`drive_distance`, `drive_arc`) still do.
- **Glare on the test floor** (dark glossy paint) creates fake "cross strips" next to the
  line, often together with a scratch. A real strip spans both sides of the line.
- **Spin deadband is around 50 raw on this floor**, not the 28 in `line_follow.py`. A spin
  commanded at +/-44 did not move the robot, so the aim angle never changed and the run
  ended `stale`. Spins at +/-55 to +/-64 worked. Fixed in code (see "Code changes").
- **Stale-frame stops** can also come from a camera hiccup (fps dips toward ~11 during
  spins; the limit is 0.5 s without a frame). Check whether the log rows were still
  changing before blaming the camera.
- After an `/mcp` reconnect the camera stream needs a warmup; `start_line_follow` enforces it.
- `take_photo` only works while a recording is running; use `look()` otherwise.
- The competition surface (white melamine) should be easier than the test floor.

## Findings from the first full AUTO run (2026-10-03)

Full course completed in six follower starts and five recoveries (nudges of 8-30 deg and
restarts). What it taught us:

- **False finishes are the most common stop on this floor.** Three of six stops were chipped
  paint or a worn/peeled stretch of tape being read as a cross strip. Always confirm with the
  contact sheet AND a raw `look()` before accepting `finish_candidate`. Use `ignore_finish_s` of about
  6-8 s to get past a known patch; shorter near the end of the course.
- **The old detector MISSED the real finish** (fixed 2026-10-03, see "Code changes"). The T was
  flagged on three frames, but the rule wanted two *consecutive* frames and a glared frame
  broke the run, so the script reported `lost` after the robot drove over it. Now a hit
  count over a window is used and `end_of_tape` exists. Still check a `lost` for a crossbar.
- **Start gate needs 3 bands.** After a sharp turn the line may show only 2 bands (it is
  leaving the analysis zone). Nudge toward the line and re-check `line_view`; retry once if a
  fresh `line_view` shows 8 bands but the gate disagrees (a transient frame).
- **Camera fps sagged from ~16 to ~10-11 over a long session.** Slow frames add lag, and the
  robot then weaves (spin right, spin left). Cause not found. If the weaving gets bad, check
  the phone (heat, battery saver, Wi-Fi) before blaming the controller.
- **Sharp corners:** the line leaves the frame at the side the corner turns toward. Nudge
  that way by 20-30 deg (right 25-30 and left 30 both worked), then restart.
- **Frozen log values mean a stall.** If consecutive status polls show identical offset, aim
  and spin command while frames keep arriving, the robot is not moving. Stop it, look, nudge,
  restart; don't wait for `stale`.
- **A start-of-course restart is fine** after turning 180 deg: the follower doesn't care
  which direction it faces, only that the line is in view.

## Lessons from the second full run, the reverse direction (2026-10-03, new controller)

- **Check the start, not just the gate.** The first start of this run began with the line 4 in
  off-center and pressed against the left edge of the frame (the detector zeroes the border), next to a
  crossbar, and the follower locked onto the chipped-paint scar on the right edge instead.
  It spun right for 3 s and drove off the line. Before `start_line_follow`: the tape should be
  roughly centered and the green dots in `line_view` must be on the tape (not on paint). If the
  robot ends up lost after a bad start, undo the rotation using the IMU yaw before and after
  (it was 38.7 deg right), then look for the tape.
- **Sunlight and window-frame shadows** produce soft dark bars and crosses that the detector
  reads as a line and as a cross strip. The raw images tell them apart immediately: a shadow has
  soft edges, tape has sharp ones. At the very end of the run the follower was tracking a
  shadow band beside the real tape.
- **The new finish rule fires on paint, floorboard seams and shadow crosses** (three false
  candidates in one run, plus one real one). That is expected and cheap: look at the raw frames,
  then restart with `ignore_finish_s` of 5-6 s.
- **Sharp bends overshoot.** At a ~50 deg right bend the robot kept going straight for a moment
  (camera and motor lag), the tape slid out of the corner of the frame, and the run ended `lost`
  after 40 s. A nudge of about the bend angle toward the side the tape left from recovered it.
  The stall boost fired once on that run (boost 16, spin 80) and the spin completed.
- **A real far-end T looks like the first one:** a crossbar with its stem coming from the
  bottom of the frame. Both ends of this course have one.

## Code changes made 2026-10-03 (after the first full run)

All in `line_follow.py` unless noted; checked in `line_follow_sim.py` (84 runs all arrive; with
the stall boost off 22 of the sticky-floor runs time out) and by replaying the recorded runs.

- **Forward and turn limited separately.** `F_MAX = 64` is the highest forward effort
  (`start_line_follow`'s `speed_pwm` cap, was 70). Turning may take the outer wheel to
  `TURN_OUTER_MAX = 100` (was 90), spins go up to `T_SPIN_MAX = 85`. `OUTER_MAX` and
  `T_DEADBAND` stay as they were because `person_track.py` (turn_to_me) imports them.
- **Spin breakaway floor.** A spin never commands less than `T_SPIN_MIN = 52`.
- **Stall boost.** If a spin's aim angle hasn't shrunk by 1 deg in 0.6 s, add 8 to the spin
  effort (repeatedly, up to the ceiling); forward effort is untouched. The boost resets when
  the spin ends or flips direction. Visible as `info.boost` in `line_follow_status`.
- **Finish is a hand-off.** `finished` became `finish_candidate`: fires when the strip is at
  least 0.28 down the frame and at least 2 of the last 5 frames had a cross strip (not
  necessarily consecutive). On a replay of the last run it fires 1.3 s before the old `lost`.
  It is also more sensitive to paint patches than before (it fires a few seconds earlier on
  the patch that fooled it), which is the intended trade: a stop costs seconds, a missed
  strip costs the run.
- **`end_of_tape`.** If the line is lost within 3 s of a cross strip being in view, the status
  is `end_of_tape` instead of `lost`.
- **`line_follow_report` returns raw (unannotated) images too:** annotated sheet, raw sheet,
  annotated still, raw still. Pass `raw=false` for the old output.
- Not changed: pure-pursuit steering, camera reader, IMU gate, `ignore_finish_s`. Not tried
  on the robot yet: only the simulator and recorded-video replays.

## PWM rules of thumb (from the user, 2026-10-03)

Straight and turning behave very differently, so don't scale them together:

- **Straight (forward) PWM is very sensitive.** A small increase gives a big change in
  speed, so move it in small steps and keep its ceiling modest. The current cruise (58) and the
  top end used for straights are probably too high for driving straight.
- **Turning PWM often has to be large.** Wheel scrub, a crack, a small stone or a sticky spot
  can need a big command to break free. Spins that were too gentle (+/-44) stalled; +/-55 to
  +/-64 turned. The upper limit for turns is about right and could go a little higher.
- So when choosing efforts by hand (`jog`, `turn_degrees`), use **gentle, small increments on
  forward** and **generous effort on turns**, and don't raise both together when something is
  stuck. For a stuck turn, raise the turn effort and leave the forward effort alone.

## Tools to use

`line_follow_report` (the main one), `line_view` (live look, also mid-run),
`line_follow_status`, `look`, `turn_degrees`, `start_line_follow(ignore_finish_s=...)`,
`stop`.

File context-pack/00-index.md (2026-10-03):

# eLlama — Design Context Pack

A four-wheel-drive outdoor robot platform. The base ships with a handheld controller; you bring
the battery, and optionally a single-board computer, camera, lidar, and any sensors you need.

## Contents

| File | Covers |
|---|---|
| `01-overview.md` | What it is, who it's for, what is bring-your-own |
| `02-physical-design.md` | Size, weight, geometry, and why each was chosen |
| `03-drivetrain-power.md` | Motors, wheels, battery, and the tradeoffs behind them |
| `04-control-architecture.md` | Design principles only — protocol is in flux |
| `05-battery-options.md` | The three supported battery options and the rules for all of them |
| `06-manufacturing-cost.md` | BOM, in-house fabrication, batch plan |
| `07-simulation.md` | The calibrated desktop simulator, sending commands from off-board compute, and the off-board-compute product vision (lawn mowing) |
| `eLlama User Manual.md` | The product manual: specs, getting started, safety |
| `bom.csv` | Current bill of materials (robot and controller, no battery) |
| `battery_bom.csv` | Prices for the three battery options |
| `Testing.csv` | Test log |

## Naming

The product is named **eLlama**.

Hardware names:

| Name | What it is | Firmware |
| --- | --- | --- |
| Llama Motor Board | Green PCB with the ESP32 DevKit (socketed), 2x4 driver headers and a power terminal. Only this board has been built so far. | `robot_motor_bts7960` |
| Llama Encoder Board | Future PCB for the two AS5600 encoders (not built yet; prototype is on a breadboard) | `robot_encoders_as5600` |
| Llama Relay Board | Future PCB for relays (not built yet) | none yet |
| Llama motor board mount | 3D-printed housing that attaches the Llama Motor Board to the robot | none |
| Motor driver mount | 3D-printed part that holds the four BTS7960 modules | none |
| BTS7960 driver modules | The four blue off-the-shelf boards | none |

Future boards follow the pattern "Llama <function> Board" and "Llama <function> board mount".

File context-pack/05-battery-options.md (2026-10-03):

# 05 — Battery Options

eLlama ships without a battery. You bring one, the same way you bring your own compute.
There are three supported choices. Pick one, charge it off the robot, and plug it in.
The robot has no charging circuit and no dock.

Current prices for each choice are in `battery_bom.csv`.

## The three options

| | A: 12 V SLA | B: 18 V tool pack | C: 12 V LiFePO4 |
|---|---|---|---|
| Part | 12 V 7 Ah sealed lead-acid, F1 terminals | 18/20 V (5S) cordless-tool pack | 12.8 V LiFePO4 with a built-in BMS |
| Tested | Yes | Yes, with a Milwaukee M18 2 Ah | **Not yet** |
| Voltage at the robot | about 11.5–12.8 V | about 16–21 V | about 12–14.4 V |
| Speed at the same command | baseline (about 1 m/s) | noticeably faster | expected to match A |
| Weight | about 4.85 lb each | lighter than SLA | lighter than SLA |
| Connection | F1 terminals, as built | printed receiver with metal contacts | F1 or the pack's own terminals |
| Charging | any 12 V SLA float charger | your tool charger | a LiFePO4 charger |
| Good if | you want the cheapest, easiest start | you already own the tools | you want light weight at 12 V |

You can run one or two SLA batteries in parallel. A second battery adds capacity, not
voltage.

## Rules for every option

- **Voltage window: 12 V to 21 V, no higher.** The motor drivers and the 5 V converter
  are the limit. A 5S tool pack (18 V nominal, about 21 V fully charged) is inside it.
  Do not use 36 V, 40 V, 56 V or 60 V packs, and do not use a 6S (24 V) pack.
- **Use a battery with protection.** Tool packs and LiFePO4 packs have a BMS. A bare
  lithium cell does not, and eLlama does not supply one.
- **Fuse and switch stay on the robot.** The 40 A main fuse and the main power switch
  sit between the battery and everything else. Do not bypass them.
- **Check polarity before the first connection.** Red is positive. An adapter wired
  backwards will damage the motor board.
- **Charge off the robot.** Take the battery out, or disconnect it, and use its own
  charger.
- **Switch the robot off when you are done.** Leaving it on drains the battery, and
  lithium packs and SLA both dislike being run flat.

## Option A: 12 V SLA

This is the baseline the robot was designed and calibrated on. A 12 V 7 Ah SLA is
available at any hardware store, auto parts store or alarm supplier. It is the heaviest and
cheapest choice. Runtime is roughly 1.5 hours per battery at working duty, which is an
inference from logged voltage drop and not a measurement.

## Option B: 18 V tool pack

Tested with one Milwaukee M18 18 V 2 Ah pack. It worked well and was faster than two SLA
batteries. A printed receiver holds the pack, but the contacts that carry current must be
metal. Printed plastic must never be the conductor.

Things to know:

- **It is faster.** The firmware sends duty cycle, so motor voltage is the duty cycle times
  the pack voltage. At the same command a 5S pack runs the motors well above SLA voltage.
  Speed also changes with the pack's charge level.
- **Calibrate it.** The PWM numbers in `ROBOT_CHARACTERIZATION.md`, the 125 PWM ceiling in
  the MCP server, the limits in `DRIVING_POLICY.md` and the simulator speed model were all
  measured on SLA at about 12.5 V. Re-run `calibration/characterize_speed.py` on a tool
  pack before relying on them, and start lower.
- **Packs differ.** Protection circuits vary between brands and between models, and a
  trip under load cuts the drive power mid-run. Only the M18 2 Ah has been tested. Other
  18/20 V packs are expected to work but are not listed as supported until someone runs
  them.
- **Wiring.** The wiring diagram for this option is `images/wiring_diagram_fuel20v.png`.

## Option C: 12 V LiFePO4

**Not tested yet.** At 12.8 V nominal it should behave like SLA, so the existing
calibration should hold, but that is an expectation and not a result.

Things to know before buying:

- **Check the BMS rating.** Many small LiFePO4 batteries carry a 10 A or 20 A BMS. Four
  brushed motors can draw more than that at start-up or under load, and a BMS trip will cut
  power. The robot's real peak current has not been measured. Prefer a pack whose BMS is
  rated well above what you measure.
- **Use a LiFePO4 charger.** An SLA float charger is the wrong profile.
- **Check the terminals.** Not every pack has F1 spade terminals.

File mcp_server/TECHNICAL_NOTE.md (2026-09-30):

# Letting an AI agent drive a real robot: measured results and safeguards

eLlama is a hand-built four-wheel-drive outdoor robot (RS550 motors with 100:1 gearboxes,
10 in wheels, 12 V, ESP32 control). This note describes an [MCP server](README.md) that lets
an AI agent drive it with closed-loop tool calls, such as "go forward 10 inches" or "turn 90
degrees left", instead of open-loop "run the motors for N seconds" commands, and what was
measured while building it. Every number below comes from a logged run in
[`calibration/`](../calibration/) and is written up in full in
[`ROBOT_CHARACTERIZATION.md`](../ROBOT_CHARACTERIZATION.md).

## How it works

The agent calls tools; the server talks to the robot over USB serial through a bridge ESP32.

- `drive_distance` stops on **wheel-encoder** ticks. `turn_degrees` stops on **IMU gyro yaw**.
  `drive_arc` follows a curved path. `read_telemetry` and `look` (a phone camera on the robot)
  give the agent state to reason about between moves.
- Every tool that can move the robot requires `confirmed_safe=true`, which the agent may only
  set after asking the human operator about that specific move. The robot has no obstacle
  sensors, so the server cannot verify that the area is clear on its own.
- Each move stops and settles before starting, is capped in size and PWM, and sends `stop` when
  it ends, however it ends.
- The bridge firmware drops to listen-only if no command arrives for 500 ms, so a crashed agent
  does not leave the robot driving.

## Measurements (unit 1, painted wood floor, re-run 2026-09-29)

**Encoders overstate in-place turns.** Wheel scrub makes the wheels turn about 1.7x as much as
the chassis does: the encoder-differential estimate read about 150 degrees for each real 90
degrees at PWM 80 and above. On 2026-09-27 the same effect read about 2x (92 degrees estimated
against about 47 degrees observed by eye, with the IMU at about 49). The IMU tracked the real
turn, so `turn_degrees` uses it as the stop condition. After the change, a 90 degree request
landed at 91 to 102 degrees depending on speed, with overshoot growing from about 1 degree at
PWM 60 to about 12 degrees at PWM 125.

**Speed is repeatable and roughly linear above a deadband.** Forward and reverse agree within 3%:

| PWM | Forward (in/s) | Reverse (in/s) |
| --- | --- | --- |
| 50 | 3.92 | 3.82 |
| 60 | 5.92 | 5.87 |
| 80 | 9.28 | 9.23 |
| 100 | 11.91 | 11.59 |
| 125 | 14.32 | 14.33 |

Nothing moves at PWM 40. The curve reproduced the 2026-09-27 run within about 4%. A stop
command overshoots the target by about 1 in at PWM 50 and about 5 in at PWM 125 on a 12 in move.

**The right side is slightly stronger.** Over three forward and three reverse runs of 30 in at
PWM 80, the right wheel covered 4 to 6% more distance than the left in both directions (one warm-up
run showed 10%). The IMU showed about 3 degrees of left curve going forward and 3 to 4 degrees of the opposite
sign going in reverse, so a forward-and-back trip largely cancels. The same bias shows up in turns:
right turns run 36% faster than left at PWM 60, shrinking to 3.5% at PWM 125. Repeat runs agree
closely (the last two forward runs are within 0.2 degrees of IMU yaw), so the drift is systematic and
a controller can correct for it.

**The failsafe works.** Command-to-motion latency is 0.195 s, set by the motor board's PWM ramp
rather than the radio link. With the controlling process killed mid-drive (`kill -9`, no
graceful stop), the robot stopped in about half a second, matching the firmware's 500 ms timeout.

## What the safeguards are for

An agent given a physical robot tends toward the same mistakes: picking the PWM value that makes a
result easiest to see, applying it at full magnitude at once, treating a direction reversal as a sign
flip, and chaining moves as if each one started clean, the way they would in a simulator.
[`DRIVING_POLICY.md`](../DRIVING_POLICY.md) exists because of that, and the server enforces the
mechanical parts of it in code: ask before every move, start low and ramp, stop before reversing,
and check state between moves. The policy stresses that a real robot has no reset. A wrong command
can flip it or damage it, and nothing undoes that.

## Limits

- **No obstacle sensing.** Wheel encoders and an IMU tell the agent how far it went, not whether the
  path was clear. This is why every move needs a human confirmation. The `look()` camera is advisory
  only and does not replace it.
- **Per-unit numbers.** The tables above describe one unit, on one surface. Hand-built units differ
  in wheel alignment, and the calibration scripts (`characterize_speed.py`, `characterize_turns.py`)
  are meant to be re-run per robot. Some encoder and PWM sign constants in `robot_server.py` are
  still hard-coded to one unit.
- **Uncalibrated track width.** `track_width_in` is still a 20 in placeholder, so the encoder turn
  estimate is only a rough figure. This does not affect `turn_degrees`, which uses the IMU.
- **IMU drift.** Yaw is gyro-integrated, which is fine for turns lasting a few seconds. Drift over
  multi-minute sessions has not been characterized.
- **Distances are not independently ground-truthed on this run.** The 2026-09-29 distance runs match
  what the operator saw on the floor and match the earlier tape-measured 30 in run, but no tape
  measurement of lateral offset was logged for the drift test.
- **Small sample.** Each sweep is one pass over the PWM range, and the drift test is three runs per
  direction.

## Try it

The server, firmware, calibration scripts and full logs are in this repository, under the
[MIT License](../LICENSE). Setup and the tool reference are in [`README.md`](README.md); read
[`DRIVING_POLICY.md`](../DRIVING_POLICY.md) before sending any drive command.

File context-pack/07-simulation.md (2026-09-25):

# 07 — Simulation

## A calibrated dry run, not a guess

eLlama has no wheel encoders or other odometry — every drive command is open-loop PWM and
duration, sent and forgotten (`04-control-architecture.md`). That makes a simulator that
just *looks* plausible worthless; it has to actually predict what the robot will do.

The simulator (`simulation/`) earns that by being calibrated against the real robot rather
than modeled from spec sheets. Simple commands were run on the physical robot, the actual
distance and turn were measured on the ground, and the simulator's speed and turn-rate
model was fit to those measurements. The result holds up well enough to plan on: straight
runs under about 8 ft land within a fraction of an inch of the simulated endpoint. Turns
drift more, since a 4-wheel skid-steer chassis scrubs sideways unpredictably, but the
simulator models that scrub too rather than ignoring it.

## Start low: generated commands default to fast

Every simulator UI requires a MAX PWM ceiling before it will run or export a path, and
there is deliberately no built-in default value.

The reason: click-to-waypoint planning — and, more generally, any motion code asked to
"get to this point" — tends to reach for the fastest PWM that satisfies the request,
since that's the straightforward solution and nothing tells it otherwise. The same bias
shows up in AI-assisted or AI-generated control code more broadly: asked to move a robot
from A to B, the natural output drives at whatever speed accomplishes that, which in an
unconstrained PWM range means close to maximum. A planned path that looks reasonable on
screen can be startlingly fast the first time it runs on hardware.

The rule that earns: start with the lowest PWM that's still effective, watch it run, and
only raise the ceiling once the path is trusted — whether it came from clicking
waypoints, typed commands, or anything a person or an LLM wrote to drive the two-number
interface. This is a property of the interface, not of the simulator specifically: the
same caution applies to any code that ends up calling `computer_bridge.ino`,
`robot_motor_bts7960.ino`, or the ESP-NOW link directly. Separately, PWM magnitudes much below
~40 tend not to move the robot at all — mechanical static friction, not a firmware
deadband — so a low-PWM command can look fine simulated and simply do nothing for real.

## A third way to send commands

`04-control-architecture.md` names two senders for the two-number interface: the handheld
controller, and onboard compute talking to the motor board over ESP-NOW. The simulator
adds a third, off-board one — a laptop or desktop, not the robot, doing the sending.

Plan a path visually in the simulator, export it as a CSV, then replay it with
`send_csv.py`: an ESP32 flashed with the unmodified `computer_bridge.ino`, plugged into the
same computer, streams the commands straight to the robot's motor board over ESP-NOW,
exactly as if a Pi onboard the robot had sent them. Nothing about the robot changes; as
far as the motor board is concerned this is indistinguishable from any other sender.

That is the same "compute is an expansion, not a dependency" argument as onboard compute,
just relocated. The planning, the simulation, the operator — none of it has to be within
arm's reach of the chassis, or even on it.

## Where this goes: attachments with no brain of their own

Push that off-board-compute pattern to its conclusion and it stops being a workflow
convenience and starts being a product shape: an attachment that carries no compute of its
own at all, because the compute never left your desk.

A lawn mower attachment is the clearest version. The mower deck itself only needs to be
cheap and mechanically robust — it never runs a model, never plans a route, never needs an
SBC riding along to get dinged by a branch or rained on. All of that lives on a desktop
computer at home: plan the mowing path in the simulator against your yard's actual
geometry, verify it clears the flower beds and the fence, then deploy the robot and drive
that path with the desktop and its ESP32 bridge, the same way as above. The robot stays
dumb and disposable; the part that's expensive and needs upgrading over time never leaves
the house.

This is also what makes the platform attachment-agnostic rather than mower-specific. The
same pattern — dumb chassis, brain left at home, path planned and calibrated in the
simulator first — applies to anything that reduces to "drive this route": patrol, a fixed
inspection loop, hauling between two points (`01-overview.md`). The mower is just the
sharpest example of why that split matters.

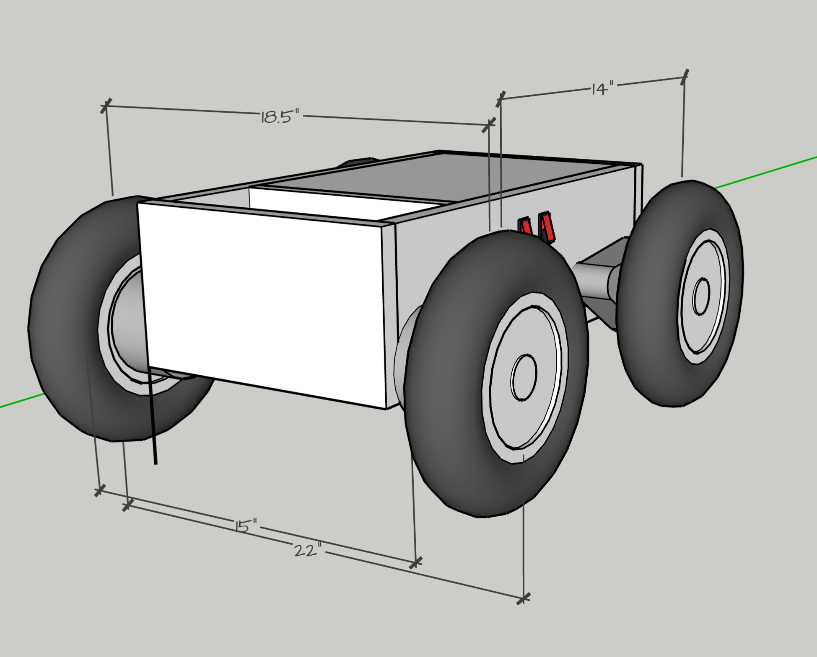
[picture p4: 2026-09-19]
images/chassis_dimensions_isometric.png

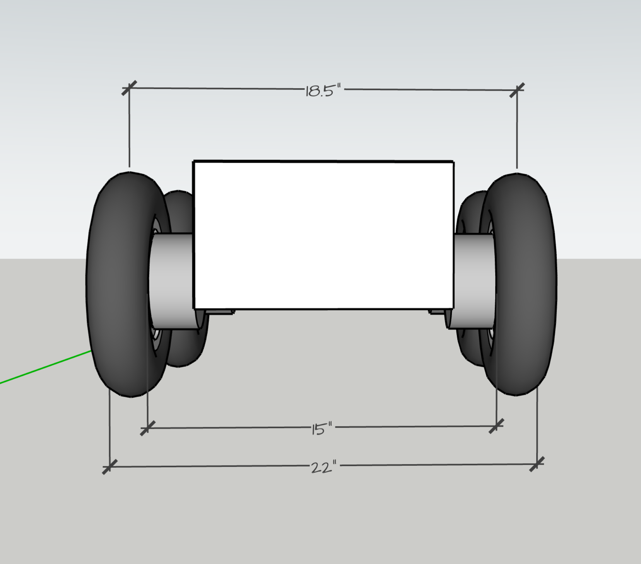
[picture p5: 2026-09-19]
images/chassis_dimensions_front.png

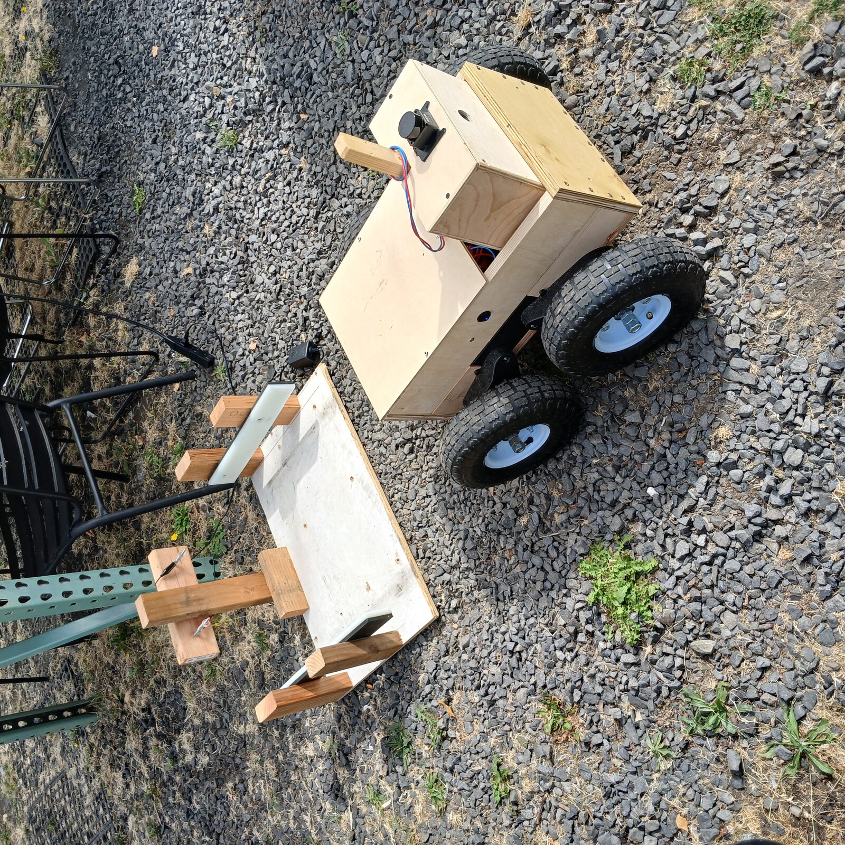
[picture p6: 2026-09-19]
images/robot_and_dock1.jpg

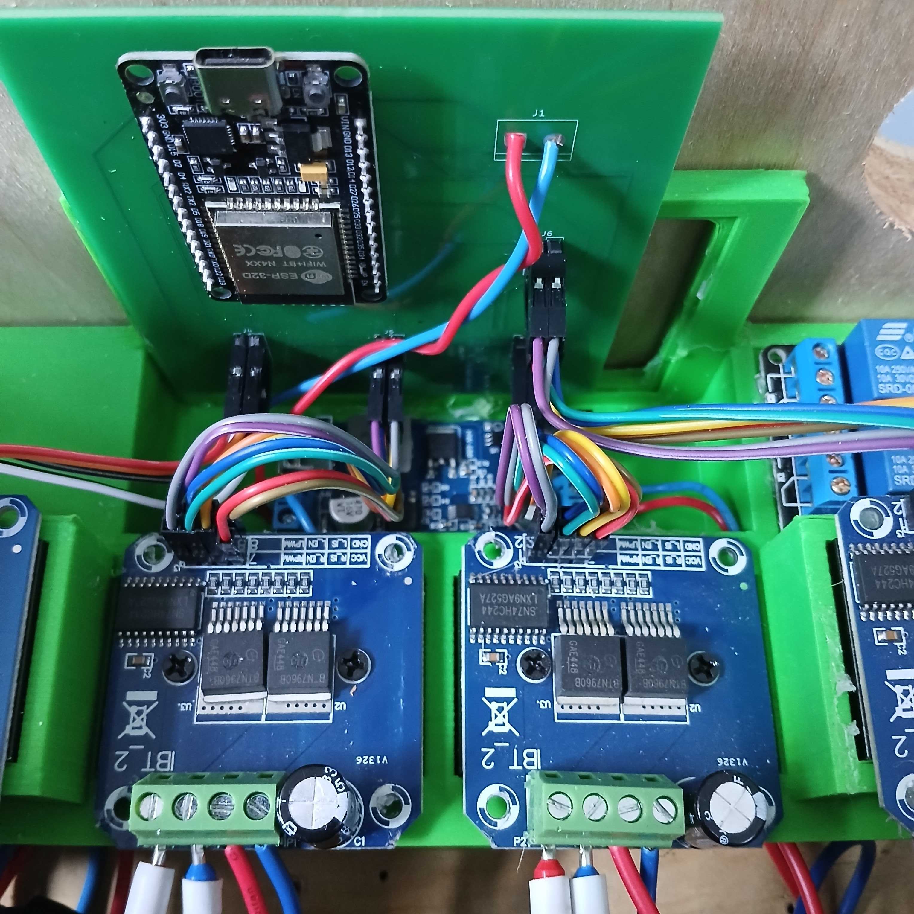
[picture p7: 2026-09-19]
images/carrier_pcb_drivers_closeup.jpg

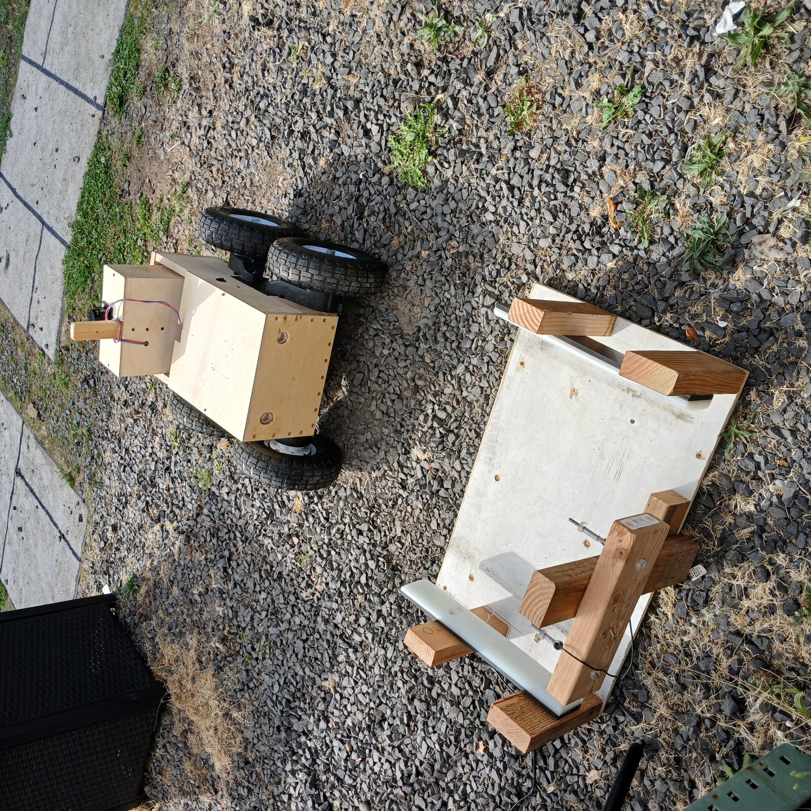
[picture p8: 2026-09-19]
images/robot_and_dock2.jpg

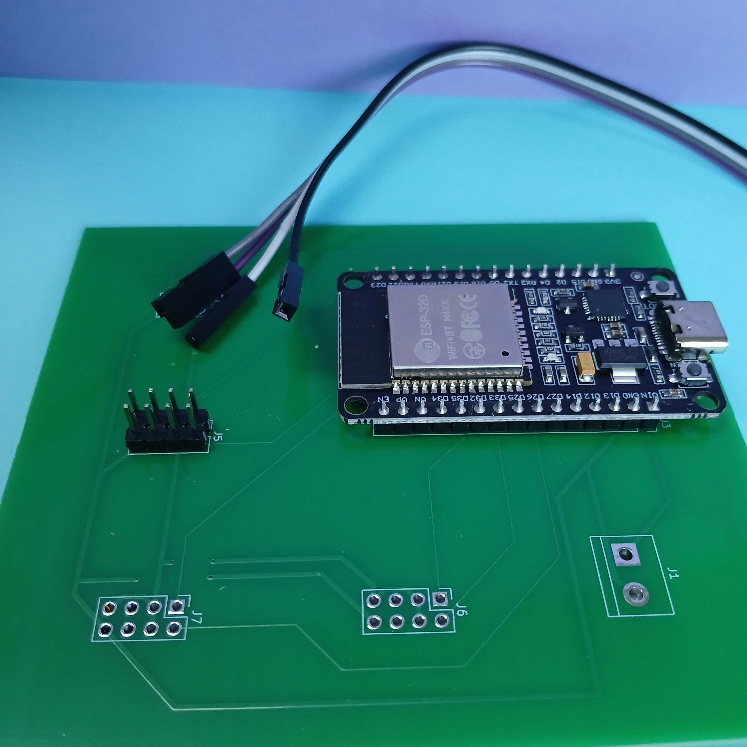
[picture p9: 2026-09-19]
images/carrier_pcb_esp32_mounted.jpg

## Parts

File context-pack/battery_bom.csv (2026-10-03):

Battery options BOM - bring your own battery (prices are a web snapshot from 2026-10-03; re-check before relying on them)
Option | Item | Description | Nominal V | Qty | Unit $ (low) | Unit $ (high) | Status | Charger | Notes
A: 12 V SLA | Battery | 12 V 7 Ah sealed lead-acid with F1 terminals (ExpertPower EXP1270 or equivalent) | 12 | 1 | $19.99 | $28.45 | Tested | Any 12 V SLA float charger | One battery runs the robot; a second in parallel adds capacity, not voltage. Retail range from ExpertPower direct to eBay.
A: 12 V SLA | Second battery (optional) | Same part wired in parallel | 12 | 1 | $19.99 | $28.45 | Tested |  | Adds runtime only.
A: 12 V SLA | Charger | Cen-Tech 12 V 2 A SLA charger (Harbor Freight) |  | 1 | $20.00 | $20.00 | Tested |  | Carried over from the old master BOM; price not re-checked.
A: 12 V SLA | Terminals | F1 style terminal connectors for 14 AWG wire (two red, two blue) |  | 4 | $0.10 | $0.10 | Tested |  | Carried over from the old master BOM.
B: 18 V tool pack | Battery | Milwaukee M18 REDLITHIUM CP2.0 (48-11-1820), 2 Ah | 18 | 1 | $109.00 | $148.00 | Tested | Brand charger (you probably own one) | This is the pack the robot was tested with. Most retailers $119-137. Skip this line if you already own one.
B: 18 V tool pack | Battery (larger) | Milwaukee M18 REDLITHIUM XC5.0 (48-11-1850), 5 Ah | 18 | 1 | $100.01 | $209.00 | Not tested | Brand charger | MSRP about $169; $100 was a sale price. Not run on the robot yet.
B: 18 V tool pack | Adapter | Printed pack receiver with metal contacts and a lead to the robot |  | 1 | TBD | TBD | Tested |  | Not priced. Contacts must be metal; do not rely on printed plastic to carry current.
C: 12 V LiFePO4 | Battery | 12.8 V 10 Ah LiFePO4 with 10 A BMS (typical Amazon listing) | 12.8 | 1 | $31.00 | $40.00 | Not tested | LiFePO4-specific charger (14.4-14.6 V) | A 10 A BMS is probably too small for four RS550 motors and may trip under load. Prefer a BMS rated for the robot's real peak current.
C: 12 V LiFePO4 | Battery (larger BMS) | 12.8 V 20 Ah LiFePO4 with 20 A BMS | 12.8 | 1 | $49.99 | $129.99 | Not tested | LiFePO4-specific charger | Range runs from budget brands to ExpertPower at the top. Still a 20 A BMS; peak current not yet measured.
C: 12 V LiFePO4 | Charger | LiFePO4 charger matched to the pack |  | 1 | TBD | TBD | Not tested |  | Not priced. Do not use an SLA float charger.
C: 12 V LiFePO4 | Terminals | F1 or the battery's own terminal type |  | 1 | TBD | TBD | Not tested |  | Check the pack's terminals before buying.

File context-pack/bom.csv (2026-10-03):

Master BOM — all assemblies, one sheet
Assembly |  | Item | Description | Manufacturer | Qty | Unit $ | Ext $ | Current source | Mouser / CS-ecosystem option | Origin of Manufacture | Link
Robot, Controller | Electronic | ESP32 DevKit V1 | MCU | Generic | 2 | $6.00 | $12.00 | Amazon | Yes — ESP32-DevKitC-32E | China | https://www.amazon.com/dp/B0DSZFD1SD?ref=ppx_yo2ov_dt_b_fed_asin_title&th=1
Robot | Electronics | Llama Motor Board | PCB that carries the ESP32 and the headers that accept the ribbon cables to the motor driver modules | PCB Board Fab | 1 | $4.00 | $4.00 | JLCPCB | No (custom) | Taiwan | jlc
Robot | Structure | Motor driver mount | Holds the four BTS7960 driver modules | self-made (printed) | 1 | $2.00 | $2.00 | In House | No (custom) | USA
Robot | Powertrain | Hub Adapter | Adapts gearmotor to wheel barrow hub | self-made (printed) | 4 | $1.00 | $4.00 | In House | No (custom) | USA
Robot | Powertrain | Hub Bolts | 5/16” x 1.5” long hex bolts with washer and nut | Generic | 8 | $0.60 | $4.80 | Lowe’s | No | China
Robot | Structure | Lug Nuts | ½” nylock nut | Generic | 4 | $1.00 | $4.00 | Lowe’s | No | China
Robot | Structure | Axle Blocks | Blocks to retain ½” allthread axles | self-made (printed) | 4 | $1.00 | $4.00 | In House | No (custom) | USA
Robot | Electronic | BTS7960 43 A driver module | Motor Driver | Generic | 4 | $5.50 | $22.00 | Amazon | Partial – drivers are 4x the cost and ½ the capacity | China | https://www.amazon.com/dp/B09QKFFDQ3?ref=ppx_yo2ov_dt_b_fed_asin_title&th=1
Robot | Electronic | 2x4 IDC F-F ribbon cable | Cable to go from Llama Motor Board to BTS7960 driver modules | Generic | 4 | $2.40 | $9.60 | Amazon | Yes | China | https://www.amazon.com/Pc-Accessories-Connectors-Sockets-8P-20cm-4PK/dp/B07DFBPZLJ?s=electronics
Robot | Powertrain | RS550 motor + triple spur gear reduction | Gear motor | Generic | 4 | $12.00 | $48.00 | Amazon | No | China
Robot | Electronic | Fuse Holder | Inline blade fuse holder with 14awg leads | Generic | 1 | $1.50 | $1.50 | Amazon | Yes | China
Robot | Electronic | Main | 40A blade fuse | Generic | 1 | $0.30 | $0.30 | Amazon | Yes | China
Robot | Powertrain | Wheels | 10” pnumatic wheel with 5/8” bearings | Generic | 4 | $7.00 | $28.00 | Harbor Freight | No | China
Robot | Structure | Axle | ½” all thread x 8” axle | Generic | 4 | $2.50 | $10.00 | Lowe’s | No | China
Robot | Electronic | Battery Connection wire | 14 gauge primary wire | Generic | 1 | $2.00 | $2.00 | Amazon | Yes | China
Robot | Electronic | Motors Wire | 18 gauge primary wire | Generic | 1 | $1.00 | $1.00 | Amazon | Yes | China
Robot | Electronic | Logic Power Wire | 22 gauge primary wire | Generic | 1 | $1.00 | $1.00 | Amazon | Yes | China
Controller | Electronic | Signal Wire | 22g silicone wire | Generic | 1 | $1.00 | $1.00 | Amazon | Yes | China
Robot | Electronic | Weygo Connectors | 6-bus weygo style connector | Weygo | 3 | $1.50 | $4.50 | Amazon | No | Germany
Robot | Electronic | 5 V BEC (ESP32 supply) | Buck converter for 12v to 5v | Generic | 1 | $1.00 | $1.00 | Amazon | Yes | China
Robot | Structure | Plywood base 11 x 18 in | 11”x18”x3/4” hardwood plywood | Generic | 1 | $12.00 | $12.00 | In House | No (self-fab) | USA
Robot | Structure | Plywood Axle Holder | 3”x4”x3/4” hardwood plywood w/ four holes | Generic | 4 | $1.50 | $6.00 | In House | No (self-fab) | USA
Robot | Structure | Axle Holder Screws | Sharp Point Lath Screws 1 ¼” | Generic | 24 | $0.10 | $2.40 | Lowe’s | No | China | https://www.homedepot.com/p/Teks-8-x-1-1-4-in-Phillips-Truss-Head-Sharp-Point-Lath-Screws-140-Pack-21512/100136421
Robot | Structure | Motor mount | Mounts to hold 550 motor end of motor gearbox | self-made (printed) | 4 | $1.00 | $4.00 | In House | No (self-fab) | USA
Robot | Structure | Battery tray | Battery tray (sized for the 12 V 7 Ah SLA; tool-pack adapters are in battery_bom.csv) | self-made (printed) | 1 | $1.00 | $1.00 | In House | No (self-fab) | USA
Robot | Powertrain | Wheel bushings | ½” to 5/8” bushing 3 ½” long | Generic | 4 | $2.50 | $10.00 | Amazon | No | China | https://www.amazon.com/WFCYQ-Bushings-332-Replacement-Height/dp/B0FWC5977R
Robot | Electronic | Power Switch | Round Blue LED Toggle Switch 12v 20A | Generic | 2 | $1.10 | $2.20 | Amazon | Yes | China | https://www.amazon.com/dp/B08TBZ23C1?ref=ppx_yo2ov_dt_b_fed_asin_title&th=1
Robot | Structure | Body shell | Body | self-made (printed) | 1 | $5.00 | $5.00 | In House | No (self-fab) | USA
Robot | Structure | Axle Mount Fasteners | 1/4”x20 3” carriage bolts, nut, and washer | Generic | 16 | $0.70 | $11.20 | Amazon | No | China | https://www.amazon.com/EASTPUK-Carriage-Washers-Stainless-Outdoor/dp/B0FBFKSHXG
Robot, Controller | Structure | Consumables | Consumables | Generic | 1 | $5.00 | $5.00 | In House | No | USA
Controller | Electronic | Analog thumb joystick | KY-023 Control Stick | Generic | 1 | $1.20 | $1.20 | Amazon | Yes | China | https://www.amazon.com/dp/B0F4KJ6LKG?ref=ppx_yo2ov_dt_b_fed_asin_title&th=1
Controller | Electronic | USB Cable | usb c to usb a cable | Generic | 1 | $2.00 | $2.00 | Amazon | Yes | China
Controller | Structure | Printed enclosure | Enclosure | self-made (printed) | 1 | $1.00 | $1.00 | In House | No (self-fab) | USA
Controller | Electronic | USB Battery | Consumer USB Battyer | Generic | 1 | $10.00 | $10.00 | Amazon | No | China
 |  | GRAND TOTAL (robot + controller; excludes battery and charger - see battery_bom.csv) |  |  |  |  | $237.70

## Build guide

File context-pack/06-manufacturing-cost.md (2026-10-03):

# 06 — Manufacturing and Cost

## Make vs. buy

**Bought:** everything where a commodity market has already solved the problem —
gearmotors, wheels, ESP32s, BTS7960 drivers, allthread, fasteners, plywood. The battery is
not bought at all: it is the owner's (`05-battery-options.md`, `battery_bom.csv`). This
is the sourcing philosophy from `01-overview.md` applied to procurement: buy the
ubiquitous part, and inherit its price, availability, and longevity.

**Made in-house:** the parts that are specific to this robot and that nobody sells —
motor mounts, hub adapters, axle blocks, battery tray, motor driver mount, and body
shell (all FDM printed); the plywood deck and axle capture blocks (table saw and drill
press); the fixed axles (bandsaw and bench grinder); and the Llama Motor Board
(fabricated at JLCPCB, through-hole connectors hand-soldered).

Every in-house part is documented with material, method, equipment, setup time, and cycle
time in the Manufactured Parts sheet. Setup is 5–10 minutes per part; cycle times run
0.1 h for a saw cut to 4 h for the body shell print.

## The motor board

The Llama Motor Board is a 2-layer PCB carrying a socketed ESP32 DevKit, four keyed 2×4
IDC headers for the motor drivers, and screw-terminal power.

JLCPCB fabricates the bare board only — traces, pads, silkscreen, no assembly. Pricing at
that scope moves with order quantity and whatever promo is running, so the honest number
is a range rather than one figure: a 100×100 mm bare board is well under $1 landed at
typical small-batch pricing, and one order of five landed at $7 shipped (helped by a
first-order coupon, so treat that as a favorable data point, not the steady-state price).
Either way, the bare board itself is a small fraction of the board's total cost.

Assembly is by hand: the ESP32 DevKit V1 goes on socketed rather than reflowed as a bare
module, along with a screw terminal and a handful of headers. Because the board isn't
committed to a fixed connector layout at fab time, the harness side stays flexible — the
motor and power connections are made with Dupont jumpers into those headers rather than
a cable set baked into the PCB order, so a different cable run or a one-off harness is a
matter of re-jumpering, not a new board spin.

Hand-populating the DevKit also leaves its USB-C port sitting exposed at the board edge:
the same port flashes the board and, with `computer_bridge.ino`, lets a bench PC drive the
robot directly over serial (`04-control-architecture.md`). A reflowed bare-module design
would have buried that port inside the enclosure.

Keyed connectors matter for a kit as much as they do for a factory: a connector that only
goes in one way is documentation that cannot be misread.

The boards are running in both prototype robots.

## Community and validation

- Developed and demonstrated at **Ctrl-H** (Portland hackerspace), where members see it
  doing real hauling work weekly
- Presented to **PARTS** (Portland Area Robotics Society)
- Demoed at **Teardown 2026** — Crowd Supply's own event, Portland

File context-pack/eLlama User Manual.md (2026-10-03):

# eLlama User Manual

## 1. Introduction

eLlama is a four-wheel-drive outdoor robot base, roughly the size of a large dog, that a person can lift into a car trunk. It ships as a base: chassis, four driven wheels, the Llama Motor Board, and a handheld controller. Add a battery of your own and drive it with no computer and no software.

It is also a mount for compute. A box on the front deck takes a single-board computer and whatever sensors the job needs — a camera, a lidar, an IMU. With that fitted, the same chassis becomes a teleoperated or autonomous platform.

### 1.1 Shipping Contents

- eLlama robot platform
- Onboard Llama Motor Board
- User breakout panel (battery voltage, unregulated; see 1.2.5)
- Single-Stick Controller
- Compute module (an empty bay for your own compute)

**Battery and charger not included.** You bring your own battery. Three options are supported: a 12 V 7 Ah SLA (sealed lead-acid) battery, an 18 V cordless-tool battery pack, or a 12 V LiFePO4 battery. Pick one, and charge it with its own charger off the robot. The comparison, the rules that apply to every option and current prices are in `05-battery-options.md` and `battery_bom.csv`. The specifications in this manual were measured on the 12 V SLA battery unless a row says otherwise.

### 1.2 Hardware Overview

#### 1.2.1 System Architecture

eLlama is built around a modular design. The Llama Motor Board is a custom PCB that carries an ESP32 DevKitV1 module, soldered onto the board. The BTS7960 driver modules are separate boards, held on the motor driver mount. The bare PCB (traces and holes only) is manufactured by JLCPCB; the header pins and the ESP32 DevKitV1 are hand-soldered on afterward. The Llama Motor Board routes the DevKitV1's pins to the driver modules' eight PWM channels, so the wiring is identical from robot to robot and the same firmware runs on every unit without per-robot pin remapping.

The Llama Motor Board handles receiving motor commands and ramping motor current and speed to match the drive target. The Llama Motor Board can receive command signals from the Single-Stick Controller or from a serial connection.

#### 1.2.2 Exterior Features

eLlama is shown below and includes:

- Llama Motor Board power button
- Motion stop and lockout button (high-voltage switch)

#### 1.2.3 Status Lights

There are LED indicators on the switches, as well as a battery status indicator on the rear of the robot.

#### 1.2.4 Switches

There are two switches on the robot. One switches the Llama Motor Board and power for the motor drivers; if this is switched on, the robot can be driven with the Single-Stick Controller. A second switch powers the compute module.

#### 1.2.5 Payloads

A compute module is included with the robot. Additional payloads such as IMUs, lidar, cameras, GPS, and single-board computers can be easily, safely, and securely mounted in the compute module, and powered from the breakout panel. The panel carries battery voltage unregulated: about 12 V on SLA or LiFePO4, and roughly 16–21 V on a tool pack. Check that your equipment accepts that range, or add your own converter.

#### 1.2.6 Robot Equations

```
V = (vR + vL) / 2
Theta = (vR - vL) / effective track
```

### 1.3 System Specifications

| Spec | Measurement |
| --- | --- |
| Dimension, Length | 24 in |
| Dimension, Width | 22 in |
| Dimension, Height | 10 in |
| Track Width | 18.5 in |
| Wheelbase Length | 14 in |
| Ground Clearance | 4 in |
| Mass | 37 pounds with one 12 V SLA battery (32 pounds without a battery) |
| Maximum Payload | 40 pounds |
| All-terrain Payload | 20 pounds |
| Maximum Speed | 1 m/s on a 12 V SLA battery; a tool pack runs faster at the same command |
| Turn Rate (in-place spin), low-speed setting | ~60–80°/s |
| Turn Rate (in-place spin), high-speed setting | ~150–180°/s |
| Climb Grade | 30% |
| Sideslope | 15% |
| Operating Temperature, Min | 0 F |
| Operating Temperature, Max | 100 F |
| Operating Time, Max Power Consumption | About 1.5 h per 12 V 7 Ah SLA battery; depends on your battery |
| Operating Time, Standby | 24 h |
| Battery (not included) | Your choice of 12 V SLA, 18 V tool pack, or 12 V LiFePO4 |
| Battery Charger | Not included; use the charger that matches your battery |
| User Power | Battery voltage, unregulated, fused |
| Communication | WiFi, UART serial |
| Wheel Encoders | None |
| Internal Sensing | None |
| Environmental | Rain resistant |

Turn rate was measured via frame-by-frame video tracking of robot orientation across concrete, gravel, grass, and carpet. High-speed carpet readings were the noisiest of the set (lower visual contrast for tracking against carpet tiles), which widens that end of the range without necessarily reflecting a real difference in turn rate on that surface.

## 2. Getting Started

The robot should be placed on a box so that the wheels can spin freely off the ground for initial testing. Ensure that no cords or wires can get wrapped up in the wheels.

### 2.1 Onboard Llama Motor Board

The USB port on the onboard Llama Motor Board is accessible, and users are encouraged to run custom firmware scripts.

### 2.2 Powering Up

Start with the robot, compute, and Single-Stick Controller off. Turn on the robot, then turn on either the Single-Stick Controller or the compute module, not both (see 2.4).

### 2.3 Network Configuration

If the robot is being controlled with the Single-Stick Controller, the ESP-NOW protocol is used for low-latency execution of commands. If the robot is being teleoperated or autonomously controlled, the network layer will come from the compute module.

### 2.4 Single-Stick Controller

When running the stock firmware, there is no pairing. The ESP32 in the Single-Stick Controller broadcasts a 4-byte struct, and every ESP32 that is listening will try to execute the command.

**Use one command source at a time.** Commands do not work properly when two different ESP32s are transmitting them: the motor board executes whichever packet arrives last, so the two sources fight. To ensure proper operation:

- When driving with the computer bridge, unplug the Single-Stick Controller from its battery.
- When driving with the Single-Stick Controller, put the computer bridge in listen mode (send `listen`) or unplug it.

No firmware changes are needed to switch between them.

### 2.5 Battery and Charging

There is no dock and no charging circuit on the robot. Charge the battery off the robot with its own charger, then connect it.

1. Pick one of the three battery options in `05-battery-options.md` (12 V SLA, 18 V tool pack, or 12 V LiFePO4).
2. With the main power switch off, connect the battery. Check polarity first: red is positive.
3. Keep the voltage between 12 V and 21 V. Do not use a 36 V, 40 V, 56 V or 60 V pack.
4. Switch the robot on and drive it, following section 3.1.
5. When you are done, switch the robot off, disconnect or remove the battery, and charge it with its own charger. A 12 V SLA takes a standard SLA float charger, a tool pack its own tool charger, and a LiFePO4 battery a LiFePO4 charger. An SLA float charger is the wrong profile for LiFePO4.

If you use a tool pack, the robot runs faster at the same command than it does on SLA. Run it on blocks first and start with slow speeds.

## 3. Safety Considerations

It is the user's responsibility to operate the robot in a safe manner.

### 3.1 General Warnings

Conduct initial testing with the robot on blocks so that the wheels can spin freely. Start with slow speeds.

### 3.2 Lifting and Transport

The robot can be lifted by one person using the handle on the back of the robot. If desired, the robot's main power switch can be left on during transport, as this will provide some active braking: with the drivers powered and no drive command present, each motor's two terminals are both held near ground rather than left floating, so the motor's back-EMF is shorted through the driver and resists rotation. This only works while the power switch is on — with it off, the drivers are unpowered and the outputs float. If the robot is transported in a vehicle, it is advised to chock the tires.

The eLlama robot has a flat bottom and can be lifted on a single forklift fork and loaded into a truck bed.

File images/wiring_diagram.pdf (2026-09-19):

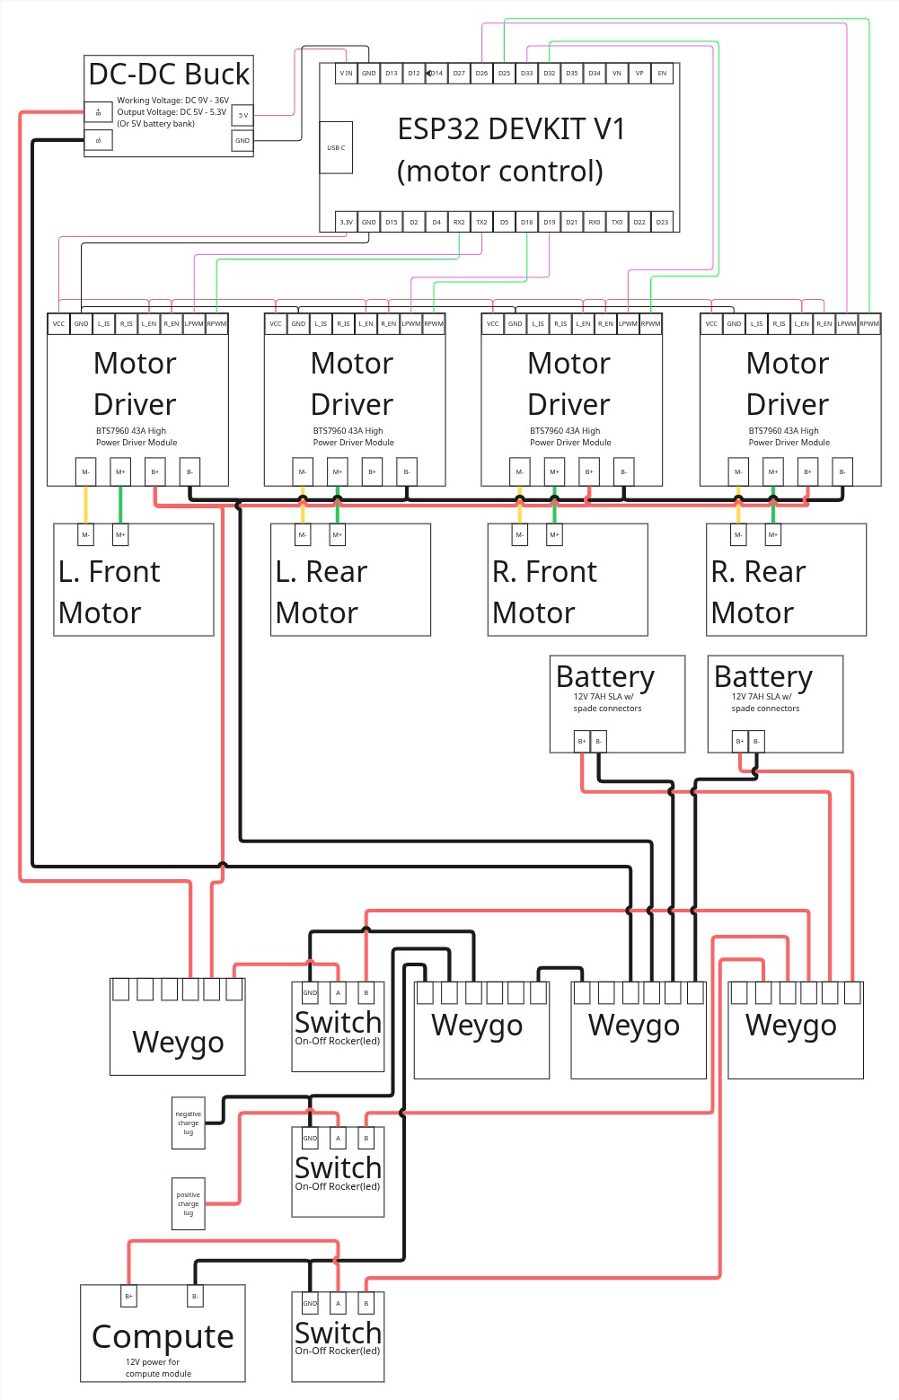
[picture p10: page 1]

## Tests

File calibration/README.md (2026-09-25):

# Calibration

Python tools that read telemetry from the ESP32 running
[`computer_bridge`](../firmware/computer_bridge/computer_bridge.ino), to validate and
calibrate the wheel encoders and IMU. The bridge is listen-only until a script sends it a
drive line, and nothing here sends one — so you can drive with the stick controller while
these run.

Needs on the robot: `robot_encoders_as5600` and a `robot_imu_*` sketch. Python: `pyserial`,
`matplotlib`.

| File | What it does |
|---|---|
| `live_view.py` | Live plots + a big readout of distance/heading since you last pressed `z`. Type `d <inches>` / `t <degrees>` to calibrate wheel diameter / track width from a real measurement. |
| `bridge.py` | Serial reader, line parsing, config load/save, and the distance/orientation math that `live_view.py` uses. |
| `config.json` | Wheel diameter, gear ratio (6.33, same as the bench sketch), track width. Read by `live_view.py`, which writes it when you calibrate. |
| `results/` | Kept measurements, e.g. the PWM → speed table. |

## Drive one foot

```
python3 calibration/live_view.py
```

1. Put the robot at a mark, press `z` in the plot window.
2. Drive one foot with the stick. The readout shows distance in inches and feet.
3. If it's off, type the measured distance in the terminal (`d 12`). The wheel diameter in
   `config.json` is rescaled and applied immediately. Press `z` and repeat to confirm.
4. For turns: `z`, spin the robot through a measured angle, type `t 90` (the real angle).
   Do the distance calibration first; the turn estimate depends on it.

`track_width_in` ships as a placeholder (20 in) — measure your wheel-to-wheel distance or
calibrate it with `t`.

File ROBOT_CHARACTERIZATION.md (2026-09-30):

# Robot characterization checklist

Goal: give Claude the mechanical numbers it can't measure on its own, so it can
drive the robot safely and build a path follower. Most data comes from the
encoders and IMU (recorded with `calibration/live_view.py --csv`); the tape
measure and video cover what those can't see: slip, real stopping distance,
and drift.

Assumptions: battery is kept above 80%, so battery level is not a variable.
The compute box (Pi, camera, lidar) is **not** on the robot. Repeat the
relevant tests if that changes the robot's mass.

## Ground rules for every test

- Robot on clear floor with at least 10 ft of free run, someone within reach.
- Any test that sends motor commands: tell Claude the robot is safe to move
  before it runs. Claude will cap PWM and always send `stop` on exit.
- Name each recording so it's obvious what it is, e.g. `--csv sweep_fwd.csv`.
- Note the floor surface and whether anything is on the robot.

## Video tips (for the tests that need it)

- Camera on a tripod or stack of books, side-on to the path, level with the floor.
- Tape measure laid on the floor along the path, in frame.
- 60 fps if the phone allows it.
- Say the test name and PWM value out loud at the start of each take.

---

## 0. Measurements by hand (5 minutes)

Write the values in the table and give them to Claude.

| Item | Value |
|---|---|
| Total mass of robot, as run (kg or lb) | |
| Wheel diameter (in) | |
| Track width, centre of left tyre to centre of right tyre (in) | |
| Wheelbase / caster position (in) | |
| Overall footprint, length x width x height (in) | |
| Roughly how high the centre of mass is (in) | |
| Wheel type and floor contact (rubber, hard plastic, etc.) | |
| Caster or skid type at the other end | |
| Where the bumpers, kill switch and battery sit | |

Also note anything you plan to add later (payload, mounts) and its mass.

## 1. PWM to steady speed (most important)

**What it tells us:** the deadband, the shape of the curve, and any left/right
motor mismatch.

**How:**
1. Put the robot where it has room, wheels free to run on the floor.
2. Claude runs a sweep: each wheel in turn, then both together, stepping PWM
   from low up to your max cap, forward and reverse, holding each step 2-3 s
   with a short stop between.
3. Encoders record steady-state speed at each step.

**You provide:** the max PWM cap you're comfortable with, and confirmation the
robot is safe to move.

**Data out:** `sweep_*.csv` from `live_view.py --csv`, plus Claude's PWM log.

> Status (2026-09-27, "unit1", robot on the ground, 4ft clear in front / 2ft behind):
> `calibration/characterize_speed.py` sweeps PWM via the MCP server's `drive_distance`
> tool, forward then reverse each step, and logs actual distance/time to a CSV — see
> `calibration/speed_characterization_unit1_20260927_201926.csv` (an earlier partial run,
> `..._201610.csv`, caught a real forward/reverse deadband asymmetry at pwm=40 — forward
> didn't move at all in 9.3s, reverse moved fine at 1.49in/s — before its own drift guard
> paused it; see that CSV and the git history of this file for the raw finding).
> Deadband is between pwm 40 and 50. Above it, forward and reverse speeds match closely
> (no meaningful asymmetry, unlike turning in place — see section 4): 50->4.11in/s,
> 60->6.13, 80->9.36, 100->12.03, 125->14.46. Roughly linear, ~0.14 in/s per PWM count
> above the deadband. Re-run the script per robot; this is unit1's curve, not a
> universal one.
>
> Re-run (2026-09-29, "unit1", painted wood, 4ft clear on all sides, pwm 40-125, 12in
> each way): `calibration/speed_characterization_unit1_20260929_172444.csv`. Reproduces
> the 09-27 curve within ~4%: 50->3.92/3.82in/s (fwd/rev), 60->5.92/5.87, 80->9.28/9.23,
> 100->11.91/11.59, 125->14.32/14.33. Deadband still between pwm 40 and 50, and this time
> pwm 40 failed to move in *both* directions (0.02in/s fwd, 0.03in/s rev), so the 09-27
> reverse move at 40 was marginal. Forward and reverse agree within 3%. A 12in request
> overshoots by +0.7in at pwm 50, +1.3 at 60, +2.8 at 80, ~+4 at 100 and ~+5 at 125
> (coast past the stop point). The 09-27 numbers above were not stale for this unit.

## 2. Acceleration and stopping

**What it tells us:** how long speed takes to settle, and how far it coasts.
This sets the safe top speed for a given obstacle-detection range.

**How:**
1. Step from rest to 3 PWM levels (low, mid, high) and hold until speed settles.
2. Cut to 0 from each level and let it coast.
3. Film the coast next to the tape measure and read the true stopping distance.

**You provide:** the video, and the stopping distance read from it for each
speed.

**Data out:** `stop_*.csv` and the video.

## 3. Straight-line drift

**What it tells us:** how much of the drift is mechanical and how much
correction a path follower needs.

**How:**
1. Lay a 10 ft tape measure along the floor and a straight line beside it.
2. Command equal PWM on both wheels and drive the full 10 ft.
3. Measure the sideways offset at the end with the tape.
4. Repeat 3 times, then repeat in reverse.

**You provide:** the sideways offset for each run and its direction (left or
right).

**Data out:** `straight_*.csv` and your offset numbers.

> Status (2026-09-27, "unit1", one run, tape-measured): `drive_distance(40, "forward",
> 80, ...)` via the MCP server. Encoders: left wheel 41.56in, right wheel 43.14in (right
> ~1.6in farther over the run) -> +4.5deg computed heading; IMU agreed closely (+4.1deg).
> User confirmed by tape: left wheel traveled ~40in as commanded, right wheel a bit
> farther, and the robot drifted **left** -- exactly matching the encoder math's sign
> convention (right-farther = left drift). This lines up with section 4's finding that
> right turns are consistently faster than left on this unit: same root cause either
> way, most likely the right-side wheel/motor having a slight speed or effective-diameter
> edge over the left. Only one run so far (not the 3x-forward + 3x-reverse the "How"
> above asks for) -- re-run for a real average and to check reverse behaves the same way.
>
> Re-run (2026-09-29, "unit1", painted wood, 3x forward + 3x reverse, 30in at pwm 80,
> odometry zeroed before each run): `calibration/drift_characterization_unit1_20260929_173403.csv`.
> Right wheel again travels farther than left in both directions: forward left/right
> 30.2/33.4, 31.5/33.3, 31.4/33.2in; reverse ~32.1/33.5in on all three. That is ~4-6%
> more on the right (10% on the first forward run, which looks like a warm-up outlier).
> IMU yaw: +2.8, +3.4, +3.2deg forward (robot curves left), -3.3, -3.3, -3.9deg reverse,
> so a forward-and-back trip largely cancels. Forward runs 2 and 3 agree within ~0.2deg IMU yaw,
> so the drift is systematic, not noise. Encoder heading reads +5 to +9deg forward vs
> ~3deg on the IMU -- the same wheel-scrub overestimate as section 4, so use the IMU for
> heading. drive_distance overshoots a 30in request by ~2.1in forward and ~2.8in reverse
> at pwm 80. Distances matched what the operator saw on the floor; no separate tape
> measurement of lateral offset was logged for this re-run.

## 4. Turning in place

**What it tells us:** the lowest PWM that turns it, the top turn rate, and how
much the wheels scrub during a turn.

**How:**
1. Spin in place at several PWM values, both directions, using the IMU yaw rate.
2. Mark a start line on the floor and do a 180 degree turn at a mid PWM.
3. Film from above or side-on and note how far off 180 degrees it ended.

**You provide:** the video and the real angle turned.

**Data out:** `turn_*.csv`, video and measured angles. Do the distance
calibration (`d <inches>`) first, because the turn estimate depends on it.

> Status (2026-09-27, "unit1", robot on the ground): `calibration/characterize_turns.py`
> sweeps PWM x direction via the MCP server's `turn_degrees` tool and logs the results —
> see `calibration/turn_characterization_unit1_20260927_200733.csv`. Turned up something
> important first: the encoder-differential heading estimate overestimates in-place turns
> by ~2x due to wheel scrub (92 deg encoder vs ~47 deg real for a commanded 90 deg turn,
> confirmed by eye) — matches this section's own hunch to use "the IMU yaw rate," which
> `turn_degrees` now does exclusively for its stop condition and reported angle. Deadband
> for turning-in-place on this unit is between pwm 50 and 60 (40 and 50 both timed out at
> 12s with negligible rotation). Turn rate at pwm 60/80/100/125: left 9.7/25.7/36.8/49.8
> deg/s, right 14.7/29.3/40.1/52.6 deg/s — right turns are consistently faster than left,
> most pronounced near the deadband (~50% at pwm 60) and converging toward parity
> (~6%) at pwm 125. Read as this unit's individual wheel-alignment asymmetry, not a
> universal number — re-run the script per robot.
>
> Re-run (2026-09-29, "unit1", painted wood, pwm 50-125, 90deg each way):
> `calibration/turn_characterization_unit1_20260929_172614.csv`. Deadband still between
> pwm 50 and 60 (at 50 left reached only 25.5deg and right 2.7deg in 12s). Turn rate at
> pwm 60/80/100/125: left 9.95/26.7/37.5/50.1deg/s, right 13.6/28.1/39.4/51.8deg/s --
> right still faster than left, +36% at pwm 60 shrinking to +3.5% at 125 (09-27: ~+50%
> and ~+6%). Achieved angle on a 90deg request (IMU): 91 at pwm 60, ~94 at 80, ~97 at
> 100, ~102 at 125, i.e. overshoot grows with speed (~1deg to ~12deg). The encoder
> estimate read ~150deg per real 90deg at pwm 80 and above, ~1.7x too high (09-27: ~2x),
> same scrub effect; the IMU stays the reliable number.

## 5. Latency and link loss (safety)

**What it tells us:** the delay from a command to movement, and what happens if
the radio link drops. `computer_bridge.ino` repeats the last command until told
otherwise, so we need to know whether the robot has its own timeout.

**How:**
1. Latency: Claude sends a step command and times the first encoder movement.
2. Link loss: with the robot running slowly, you unplug the bridge ESP32 (or
   stop the sending script) and watch whether the robot stops on its own.
   Be ready to grab it.

**You provide:** what you saw, and how long it kept moving.

> Status (2026-09-27, "unit1", robot on the ground): **Latency** — sent a raw drive
> command (pwm=60 forward) and polled encoder counts; first detected movement at 0.195s,
> consistent with `robot_motor_bts7960.ino`'s PWM ramp (RAMP_STEP/RAMP_DT_MS, ~333
> PWM/s, so ~0.18s to ramp from 0 to 60) dominating over ESP-NOW/encoder-broadcast
> latency. **Link loss** — started the robot moving slowly (pwm=50, jog) in a background
> process, let it run ~2.3s, then `kill -9`'d that process with zero graceful shutdown
> (no stop sent, no exit handler ran) to simulate a real crash, not a clean disconnect.
> User watched and confirmed the robot stopped almost immediately, "maybe half a
> second" — matching `computer_bridge.ino`'s `SERIAL_IDLE_TIMEOUT_MS=500` almost exactly.
> Confirms the firmware failsafe (added this session, see mcp_server/README.md) actually
> works against a real killed process, not just against a clean `stop`/`listen` line.

## 6. Surfaces and obstacles

**What it tells us:** how the numbers change on the surfaces you'll use.

**How:**
1. Repeat tests 1 to 3 on each surface (hard floor, carpet, etc.).
2. Try a door threshold and a small ramp, and note what it can climb and at
   what PWM.

**You provide:** surface names and the climb results.

**Data out:** separate CSVs per surface.

---

## Order of work

1. Section 0 (hand measurements) and the PWM cap.
2. Section 5 (latency and link loss), so we know the safety picture first.
3. Section 1 (PWM to speed).
4. Sections 2, 3, 4.
5. Section 6 for each new surface.

## Handing the data over

Put recordings and videos in one folder, with one line per file saying what it
is and any measurements you took. Claude can analyze CSVs with
`calibration/analyze_csv.py`; the video numbers go in your notes.

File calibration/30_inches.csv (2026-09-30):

time_s | source | dist_l_in | dist_r_in | dist_avg_in | speed_l_in_s | speed_r_in_s | enc_heading_deg | pitch_deg | roll_deg | yaw_deg | acc_x_g | acc_y_g | acc_z_g
0.199 | ENC | 0.0000 | 0.0000 | 0.0000 | 0.0000 | 0.0000 | 0.000 | 0.000 | 0.000 | 0.000 | 0.0000 | 0.0000 | 0.0000
0.199 | ENC | 0.0000 | 0.0000 | 0.0000 | 0.0000 | 0.0000 | 0.000 | 0.000 | 0.000 | 0.000 | 0.0000 | 0.0000 | 0.0000
0.199 | ENC | 0.0000 | 0.0000 | 0.0000 | 0.0000 | 0.0000 | 0.000 | 0.000 | 0.000 | 0.000 | 0.0000 | 0.0000 | 0.0000
0.199 | ENC | 0.0000 | 0.0000 | 0.0000 | 0.0000 | 0.0000 | 0.000 | 0.000 | 0.000 | 0.000 | 0.0000 | 0.0000 | 0.0000
0.199 | ENC | 0.0000 | 0.0000 | 0.0000 | 0.0000 | 0.0000 | 0.000 | 0.000 | 0.000 | 0.000 | 0.0000 | 0.0000 | 0.0000
0.199 | ENC | 0.0000 | 0.0000 | 0.0000 | 0.0000 | 0.0000 | 0.000 | 0.000 | 0.000 | 0.000 | 0.0000 | 0.0000 | 0.0000
0.199 | ENC | 0.0000 | 0.0000 | 0.0000 | 0.0000 | 0.0000 | 0.000 | 0.000 | 0.000 | 0.000 | 0.0000 | 0.0000 | 0.0000
0.199 | ENC | 0.0000 | 0.0000 | 0.0000 | 0.0000 | 0.0000 | 0.000 | 0.000 | 0.000 | 0.000 | 0.0000 | 0.0000 | 0.0000
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

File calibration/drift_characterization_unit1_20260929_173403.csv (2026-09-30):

robot_id | run | direction | pwm | requested_in | actual_in | ok | left_in | right_in | enc_heading_deg | imu_yaw_deg
unit1 | 1 | forward | 80 | 30.0 | 31.73 | True | 30.206 | 33.359 | 9.03 | 2.81
unit1 | 1 | reverse | 80 | 30.0 | 32.81 | True | -32.12 | -33.519 | -4.01 | -3.26
unit1 | 2 | forward | 80 | 30.0 | 32.37 | True | 31.515 | 33.306 | 5.13 | 3.37
unit1 | 2 | reverse | 80 | 30.0 | 32.79 | True | -32.093 | -33.475 | -3.96 | -3.3
unit1 | 3 | forward | 80 | 30.0 | 32.27 | True | 31.411 | 33.16 | 5.01 | 3.15
unit1 | 3 | reverse | 80 | 30.0 | 32.83 | True | -32.079 | -33.494 | -4.05 | -3.91

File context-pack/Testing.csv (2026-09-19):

Date | Location | Distance | Starting Voltage | Ending Voltage | Voltage Drop | Time (minutes) | GPS Data | Accel Data | Mission | Controller | Notes | Weather | Firmware | Configuration | Accessory | Image 1 | Image 2 | Image 3
10/25/2025 | Willlow Grove | 0.2 | 12.85 | 12.72 | 0.13 | 5 | run1a_10_21_25.gpx | no accel data | locomotion testing | android handset | no notes | dry | r5d2.ino | r5d2 | none
10/25/2025 | Willlow Grove | 0.15 | 12.85 | 12.62 | 0.23 | 4 | run1b_10_21_25.gpx | no accel data | locomotion testing | android handset | no notes | dry | r5d2.ino | r5d2 | none
10/25/2025 | Willlow Grove | 0.21 | 12.85 | 12.58 | 0.27 | 20 | run2_10_21_25.gpx | no accel data | locomotion testing | android handset | no notes | dry | r5d2.ino | r5d2 | none
12/12/2025 | Willlow Grove | 0.71 | 12.85 | 12.55 | 0.3 | 30 | run1_12_12_25.gpx | no accel data | locomotion testing | android handset | no notes | dry | r5d2.ino | r5d2 | none
12/13/2025 | Longview, Washington | 0.82 | 12.85 | 12.67 | 0.18 | 18.5 | run1_12_13_25.gpx | no accel data | locomotion testing | android handset | no notes | dry | r5d2.ino | r5d2 | none
12/14/2025 | Longview, Washington | 0.98 | 12.85 | 12.55 | 0.3 | 23 | run_12_14_25.gpx | no accel data | locomotion testing | android handset | used lights | dry | r5d2.ino | r5d2 | none
12/20/2025 | Longview, Washington | 0.51 | 12.85 | 12.71 | 0.14 | 12.5 | run_12_20_2025.gpx | no accel data | locomotion testing | android handset | no notes | dry | r5d2.ino | r5d2 | none
12/21/2025 | Longview, Washington | 0.37 | 12.85 | 12.82 | 0.03 | 8 | run_12_21_2025.gpx | no accel data | locomotion testing | autonamous | right wheel locked up | dry | r5d2_grid.ino | r5d2 | none
12/22/2025 | Lexington, Washington | 0.53 | 12.85 | 12.81 | 0.04 | 12 | run_12_22_2025.gpx | no accel data | locomotion testing | android handset | right wheel locked up | dry | r5d2.ino | r5d2 | none
12/29/2025 | Lexington, Washington | 1.08 | 12.85 | 12.63 | 0.22 | 25 | run_12_29_2025.gpx | no accel data | locomotion testing | android handset | rewired right wheel; no issues | dry | r5d2.ino | r5d2 | none
12/31/2025 | Longview, Washington | 0.7 | 12.85 | 12.77 | 0.08 | 16 | run_12_31_2025.gpx | run_12_31_2025.zip | locomotion testing | android handset | test with stabilizing platform | dry | r5d2.ino | r5d2 | none
01/01/2026 | Longview, Washington | 0.55 | 12.85 | 12.78 | 0.07 | 13 | run_01_01_2026.gpx | no accel data | locomotion testing | android handset | no notes | dry | r5d2.ino | r5d2 | none
01/03/2026 | Longview, Washington | 0.43 | 12.85 | 12.78 | 0.07 | 9 | run_01_03_2026.gpx | no accel data | locomotion testing | android handset | no notes | dry | r5d2_relay.ino | r5d2 | none
02/26/2026 | Portland, Oregon (Kenton) | 1 | 12.85 | 12.5 | 0.35 | 45 | no run data | no accel data | trash pickup | android handset | first run with skidsteer | dry | skidsteer.ino | r5d4 | none
02/27/2026 | Portland, Oregon (Kenton) | 0.85 | 12.85 | 12.6 | 0.25 | 60 | no run data | no accel data | trash pickup | android handset | first run with trailer | dry | skidsteer.ino | r5d4 | trailer
02/28/2026 | Portland, Oregon (Kenton) | 1.17 | 12.85 | 12.6 | 0.25 | 34 | run_02_26_2026.gpx | no accel data | trash pickup | android handset | also did a cart return | dry | skidsteer.ino | r5d4 | trailer
02/29/2026 | Portland, Oregon (Kenton) | 1 | 12.85 | 12.5 | 0.35 | 50 | no run data | no accel data | trash pickup | android handset | buttons stick after changing speeds | dry | skidsteer.ino | r5d4 | trailer
03/06/2026 | Portland, Oregon (Kenton) | 1.93 | 12.85 | 12.4 | 0.45 | 60 | run_03_06_2026.gpx | no accel data | trash pickup | single analog stick | new controller is much better | moderate rain | skidsteer_recieve.ino and skidsteer_sender.ino | r5d4 | trailer
03/09/2026 | Portland, Oregon (Kenton) | 0.01 | 12.85 | 12.8 | 0.05 | 15 | no run data | no accel data | haul cart | single analog stick | wire came unsoldered incontroller | light rain | skidsteer_recieve.ino and skidsteer_sender.ino | r5d4 | trailer -- make another trailer so that it can accomidate two buckets at the same time
9/10/26 | Portland, Oregon (Kenton) | 2 | 13 | 12.6 | 0.4 | 40 | no run data | no accel data | collect gps coords | single analog stick | tried to collect gps data, but pi shut down part of the way through | dry | motor_receiver.ino, single_analog_stick.ino, gpslog.py | r5d4 | compute box
 | Total: | 13.19 |  |  |  | 445

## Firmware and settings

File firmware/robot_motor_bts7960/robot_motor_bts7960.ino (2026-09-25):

// ===== Llama Robot: Motor Receiver (ESP-NOW, LEDC PWM) =====
//
// Runs on the Llama Motor Board.
//
// Wire format: DrivePacket{left, right} -- signed PWM per side, -255..255.
// Works with either a human joystick remote (which does its own arcade-
// drive mixing before sending) or a computer plugged into an ESP32 bridge
// (which can send raw left/right values directly). This receiver does no
// mixing -- it only ramps toward the commanded values (to protect the
// gearboxes from instant direction reversals) and writes PWM to the
// motors via the ESP32 LEDC peripheral. Stopping is just PWM 0; with R_EN/L_EN
// hardwired enabled, that holds both motor terminals near ground through the
// BTS7960 low-side switches, which actively (dynamically) brakes the motor.

#include <WiFi.h>
#include <esp_now.h>

// ================= Motor pins =================

#define FL_RPWM 16
#define FL_LPWM 17
#define BL_RPWM 18
#define BL_LPWM 19
#define FR_RPWM 32
#define FR_LPWM 33
#define BR_RPWM 25
#define BR_LPWM 26

// ================= LEDC settings =================
const int LEDC_FREQ_HZ  = 20000; // above audible range
const int LEDC_RES_BITS = 8;     // 0..255 duty, matches PWM range below

// ================= Settings =================
const int      RAMP_STEP      = 1;   // max PWM change per ramp tick
const uint32_t RAMP_DT_MS     = 3;   // ramp tick period
const uint32_t CMD_TIMEOUT_MS = 300; // stop if no packet received in this long

// ================= Wire format =================
typedef struct __attribute__((packed)) {
  int16_t left;   // -255..255
  int16_t right;  // -255..255
} DrivePacket;

// ================= State =================
int curL = 0, curR = 0;
volatile int tgtL = 0, tgtR = 0;
volatile uint32_t lastRecvMs = 0;
uint32_t lastRampMs = 0;

void setAll(int l, int r) {
  if (l >= 0) {
    ledcWrite(FL_LPWM, l); ledcWrite(FL_RPWM, 0);
    ledcWrite(BL_LPWM, l); ledcWrite(BL_RPWM, 0);
  } else {
    ledcWrite(FL_LPWM, 0); ledcWrite(FL_RPWM, -l);
    ledcWrite(BL_LPWM, 0); ledcWrite(BL_RPWM, -l);
  }

  if (r >= 0) {
    ledcWrite(FR_LPWM, r); ledcWrite(FR_RPWM, 0);
    ledcWrite(BR_LPWM, r); ledcWrite(BR_RPWM, 0);
  } else {
    ledcWrite(FR_LPWM, 0); ledcWrite(FR_RPWM, -r);
    ledcWrite(BR_LPWM, 0); ledcWrite(BR_RPWM, -r);
  }
}

// ================= ESP-NOW receive =================
void onRecv(const esp_now_recv_info_t* info, const uint8_t* data, int len) {
  if (len != sizeof(DrivePacket)) return;

  DrivePacket p;
  memcpy(&p, data, sizeof(p));

  tgtL = constrain((int)p.left, -255, 255);
  tgtR = constrain((int)p.right, -255, 255);
  lastRecvMs = millis();
}

// ================= Setup =================
void setup() {
  Serial.begin(115200);

  ledcAttach(FL_LPWM, LEDC_FREQ_HZ, LEDC_RES_BITS);
  ledcAttach(FL_RPWM, LEDC_FREQ_HZ, LEDC_RES_BITS);
  ledcAttach(BL_LPWM, LEDC_FREQ_HZ, LEDC_RES_BITS);
  ledcAttach(BL_RPWM, LEDC_FREQ_HZ, LEDC_RES_BITS);
  ledcAttach(FR_LPWM, LEDC_FREQ_HZ, LEDC_RES_BITS);
  ledcAttach(FR_RPWM, LEDC_FREQ_HZ, LEDC_RES_BITS);
  ledcAttach(BR_LPWM, LEDC_FREQ_HZ, LEDC_RES_BITS);
  ledcAttach(BR_RPWM, LEDC_FREQ_HZ, LEDC_RES_BITS);

  setAll(0, 0);

  WiFi.mode(WIFI_STA);
  WiFi.setSleep(false);

  if (esp_now_init() != ESP_OK) {
    Serial.println("ESP-NOW init failed");
    while (true) delay(1000);
  }
  esp_now_register_recv_cb(onRecv);

  Serial.println("Robot Ready.");
}

// ================= Loop =================
void loop() {
  uint32_t now = millis();

  if (now - lastRecvMs > CMD_TIMEOUT_MS) {
    tgtL = 0;
    tgtR = 0;
  }

  if (now - lastRampMs >= RAMP_DT_MS) {
    lastRampMs = now;
    curL += constrain(tgtL - curL, -RAMP_STEP, RAMP_STEP);
    curR += constrain(tgtR - curR, -RAMP_STEP, RAMP_STEP);
    setAll(curL, curR);
  }
}

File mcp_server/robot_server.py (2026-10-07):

#!/usr/bin/env python3
"""MCP server that lets an AI agent drive eLlama over computer_bridge.ino, closing the
loop on the wheel encoders instead of driving open-loop for a fixed duration.

Talks over the same USB-serial link as calibration/live_view.py and toandfro.py did --
reuses calibration/bridge.py for serial I/O, line parsing and the distance/heading math,
so there is exactly one place that logic lives.

Read DRIVING_POLICY.md before calling anything here. The short version, enforced by this
file: every tool that can move the robot requires confirmed_safe=true, which must only be
set after asking the human operator in the moment -- this server has no obstacle sensors
(no lidar, no camera) wired in, only wheel encoders and an IMU, so there is no way for it
to "see" that the area is clear. Per the operator's own stated policy, a sensor-verified
small bump forward could skip the ask -- but that only applies once real proximity/vision
sensing is actually feeding this server, which is not the case yet. Until then, ask first,
every time, regardless of move size. First-time-testing-a-new-motor and full-power moves
require asking even after obstacle sensing exists.

Setup:
    pip install mcp pyserial
    python3 mcp_server/robot_server.py            # run directly, or register with an
                                                    # MCP client (see mcp_server/README.md)

Env:
    ELLAMA_SERIAL_PORT   explicit serial port (e.g. /dev/ttyUSB0); default auto-detects
                         via calibration/bridge.py's port picker.
    ELLAMA_CAM_URL       explicit IP Webcam base URL (e.g. https://192.168.0.50:4444);
                         default scans the local /24 subnet for the phone.
"""

import array
import atexit
import json
import math
import os
import signal
import socket
import ssl
import subprocess
import sys
import threading
import tempfile
import time
import urllib.request
import wave
from concurrent.futures import ThreadPoolExecutor
from io import BytesIO
from pathlib import Path
from typing import Literal, Optional

import serial

sys.path.insert(0, str(Path(__file__).resolve().parent.parent / "calibration"))
import bridge  # noqa: E402  (calibration/bridge.py)
import recording  # noqa: E402  (mcp_server/recording.py)
import line_vision  # noqa: E402  (mcp_server/line_vision.py)
import phone_display  # noqa: E402  (mcp_server/phone_display.py)
import person_track  # noqa: E402  (mcp_server/person_track.py)
import person_vision  # noqa: E402  (mcp_server/person_vision.py)
import camera_stream  # noqa: E402  (mcp_server/camera_stream.py)
import line_follow  # noqa: E402  (mcp_server/line_follow.py)

from mcp.server.mcpserver import MCPServer as FastMCP  # mcp>=2.0 renamed FastMCP -> MCPServer
from mcp.server.mcpserver import Image
from PIL import Image as PILImage

# ---------------------------------------------------------------------------
# Safety constants -- sourced from DRIVING_POLICY.md, not guessed. If the policy
# document changes, it is right and these are stale; check it before trusting these.
# ---------------------------------------------------------------------------

# "Scripted ground-truth-run ceiling" in DRIVING_POLICY.md -- same value the deleted
# toandfro.py used for encoder-verified runs where the robot actually rolls.
MAX_PWM_CEILING = 125

# True gear ratio confirmed by calibration/30_inches.csv (a real tape-measured 30in
# straight run) -- see calibration/analyze_run.py's TRUE_GEAR_RATIO and its docstring.
# calibration/config.json still says 6.33 and is being left as-is for now, so this
# overrides it in memory only; it does not touch the file.
TRUE_GEAR_RATIO = 4.5

# Refuse to drive if the last encoder packet is older than this -- driving without live
# feedback is exactly the open-loop, no-undo situation DRIVING_POLICY.md warns about.
TELEMETRY_STALE_S = 2.0

# Pause after every stop before starting a new move, satisfying "no sign reversal without
# a stop in between" unconditionally rather than trying to detect reversals.
STOP_SETTLE_S = 0.25

# Per-call caps so one tool call can't send the robot further/further-turned than a
# human watching the chat can react to. Chain multiple confirmed calls for more --
# that is the stop-check-decide-move loop DRIVING_POLICY.md asks for, not a limitation
# to work around.
MAX_SINGLE_MOVE_IN = 60.0
MAX_SINGLE_TURN_DEG = 180.0

# jog() is open-loop and time-based, not encoder-target-based -- cap how long one call
# can run so a bad (left_pwm, right_pwm) can't run away unattended.
MAX_JOG_DURATION_S = 10.0

# computer_bridge.ino drops to listen-only if no serial line arrives for 500ms
# (SERIAL_IDLE_TIMEOUT_MS), so every drive loop re-sends its command at least this often.
# Verified 2026-09-28: without this, drive_distance(6in, pwm=50) stopped after ~3in.
DRIVE_KEEPALIVE_S = 0.1

# drive_arc() caps. A circle is one continuous closed-loop motion, so it gets its own
# path-length cap instead of MAX_SINGLE_MOVE_IN; it still aborts the moment telemetry
# goes stale. Radius floor keeps it from degenerating into an in-place spin (use
# turn_degrees for that).
MAX_SINGLE_ARC_DEG = 360.0
MAX_SINGLE_ARC_IN = 160.0
MIN_ARC_RADIUS_IN = 6.0
# How often drive_arc re-measures curvature and corrects the wheel-speed split, and how
# hard it corrects (fraction of pwm per unit of relative curvature error).
ARC_CONTROL_DT_S = 0.1
ARC_GAIN = 0.15
# With the inner wheel stopped this robot can't curve tighter than ~12.5in radius
# (measured 2026-09-28, pwm=60), so drive_arc lets the inner wheel run backwards, down to
# this PWM, for tighter circles. The wheel split changes by at most ARC_MAX_STEP_PWM per
# control step, so the inner wheel eases through zero into reverse instead of jumping.
ARC_MAX_INNER_REVERSE_PWM = int(0.9 * MAX_PWM_CEILING)  # 112; at -60 it bottomed out at ~7.9in radius
ARC_MAX_STEP_PWM = 5

# Encoder count direction when that wheel rolls forward. On 2026-09-28 this read (1, -1):
# a 6in forward drive_distance gave left +6.77in, right -6.66in. Re-verified 2026-09-29 and
# it is now (1, 1): a 22in forward drive_distance moved left +14617 ticks and right +14922
# ticks, and reversing moved both negative -- the right encoder is no longer mirrored.
# With the stale (1, -1), drive_arc's path estimate had the right wheel backwards, so its
# curvature loop never engaged on a reverse arc. Only drive_arc uses this; re-check it
# after any encoder wiring or firmware change.
ENCODER_FORWARD_SIGN = (1, 1)

# Verified 2026-09-27, robot on blocks, wheels free to spin: direction="forward" at
# +50 PWM on both sides drove all four wheels backwards, confirmed by eye. -1 makes
# direction="forward" match real forward rotation. Re-check this after any change to
# wiring, motor board firmware, or which physical wheel is "left" vs "right".
FORWARD_PWM_SIGN = -1
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

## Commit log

2026-09-19 Initial commit: eLlama robot platform
    Replaces prior repo history with current project state (design docs,
    firmware, teleop scripts, images). video_evidence/ excluded via
    .gitignore due to size.
    [Testing.csv, bom.csv]
2026-09-19 Document BTS7960 active braking at PWM 0 and add turn rate spec
    Testing confirmed the BTS7960 drivers actively (dynamically) brake at
    PWM 0 while powered, contradicting prior docs/comments that claimed
    stopping relied only on gear reduction. Corrected control-architecture
    notes and the motor_receiver.ino comment, and expanded the explanation
    in the user manual. Also added measured turn rate (low/high speed
    settings) to the manual's spec table, from spin_rate video tracking.
2026-09-19 Clean up docs and rename images to descriptive filenames
    - Remove unwritten TODO placeholders from the user manual (exterior
    features list, Status Lights heading) and the empty Orientation stub
    - Sync context-pack/00-index.md with the files actually present
    - Add root README.md and teleop/README.md
    - Rename images/ files from camera-roll numbers and "Screenshot From..."
    to names describing their content
2026-09-20 Document the calibrated simulator and the off-board-compute vision
    Add a README for simulation/ explaining the calibration story (real
    runs measured, model fit to match) and the build-path -> export ->
    send_csv.py workflow, plus the two example screenshots. Add
    context-pack/07-simulation.md covering the simulator as a third way
    to send drive commands and the lawn-mower attachment vision it
    enables (cheap, brainless attachment; compute stays on a desktop at
    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
2026-09-20 Add a required MAX PWM safety ceiling to every simulator UI
    Click-to-waypoint planning (and generated motion code generally) tends
    to reach for full-speed PWM to satisfy a path, which can run much
    faster on the real robot than expected. Each of the four simulator
    UIs now requires a MAX PWM value before RUN or EXPORT CSV will act;
    there is no default on purpose, so every command's (pwml, pwmr) pair
    is scaled down (preserving their ratio) to fit under whatever the
    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
2026-09-22 Update README to remove build documents reference
    Removed reference to wiring diagrams and related documents.
2026-09-25 Rename firmware sketches by role and add encoder, IMU and bench sketches
    Folders are now <where>_<function>_<part>: robot_motor_bts7960,
    robot_encoders_as5600, robot_imu_icm20945, robot_imu_mpu6050,
    controller_stick, computer_bridge, plus bench_*_test sketches.
    - robot_encoders_as5600: two AS5600s on separate I2C buses, 12-byte
    EncoderPacket over ESP-NOW.
    - computer_bridge: listen-only until sent a drive line ("listen" returns
    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
2026-09-25 Add calibration tools: live encoder/IMU view with drive-a-foot calibration
    live_view.py plots per-wheel distance and speed plus IMU orientation while
    driving by hand, and calibrates wheel diameter and track width from a
    measured distance or turn. Constants live in calibration/config.json.
    [pwm_speed_summary_20260920.csv]
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2026-09-25 Rename hardware terms: Llama Motor Board, Encoder Board, motor driver mount
    Docs and header-comment changes only; no code changes.
    [bom.csv]
2026-09-28 Add MCP server for encoder/IMU-closed-loop driving, verify against real hardware
    Lets an AI agent drive eLlama via closed-loop tools (drive_distance, turn_degrees,
    jog) instead of guessing an open-loop duration, gated by a required confirmed_safe
    argument per DRIVING_POLICY.md. Adds a firmware-side idle-timeout to
    computer_bridge.ino so a crashed controlling process can't leave the robot driving
    forever, verified against a real kill -9 mid-drive (stopped in ~0.5s).
    Found and fixed real issues along the way: PWM direction was inverted
    (FORWARD_PWM_SIGN), and the encoder-differential turn estimate overestimates
    in-place rotation ~2x from wheel scrub, so turn_degrees now uses IMU yaw instead.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
    [pwm_speed_summary_20260920.csv, speed_characterization_unit1_20260927_201610.csv, speed_characterization_unit1_20260927_201926.csv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]
2026-09-29 Add drive_arc, drive keepalive, and hardened GY-521 IMU sender
    Drive loops re-send their command every 0.1s so the bridge's 500ms serial
    idle timeout no longer stops long moves early. New drive_arc tool drives
    closed-loop curved paths using IMU yaw and a curvature correction loop.
    New robot_imu_gy521 sketch auto-detects the I2C address, accepts clone
    WHO_AM_I values, and recovers from disconnects.
    [robot_imu_gy521.ino, robot_server.py]
2026-09-29 Add phone camera look() tool, reverse and capped arcs, fix encoder sign
    look() returns a photo from an Android IP-camera app on the robot; the
    phone is found by scanning the local subnet (ports 8080/4444, http or
    https with a self-signed cert) or via ELLAMA_CAM_URL.
    drive_arc gains max_wheel_pwm, which caps the outer wheel so an operator's
    PWM limit holds, and travel="reverse" for backing arcs.
    ENCODER_FORWARD_SIGN is now (1, 1): both encoders count up going forward,
    so the old (1, -1) gave drive_arc a wrong path estimate and left its
    curvature loop inactive on reverse arcs.
    [robot_server.py]
2026-09-29 Add motor control board JLCPCB Gerber and drill files
    Fabrication output for the Llama Motor Board, generated 2026-08-03, kept
    in hardware/ so the exact ordered design can be re-uploaded to JLCPCB.
    [motor_control_board-B_Cu.gbr, motor_control_board-B_Mask.gbr, motor_control_board-B_Paste.gbr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]
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2026-09-30 Record 2026-09-29 unit1 re-run of speed, drift and turn characterization
    [drift_characterization_unit1_20260929_173403.csv, speed_characterization_unit1_20260929_172444.csv, turn_characterization_unit1_20260929_172614.csv]
2026-09-30 Add live_view --csv recording and CSV analysis/export scripts
    [30_inches.csv]
2026-09-30 Update system architecture diagram and document one-command-source rule
    Add the diagram to the README, fix the manual's DrivePacket size (12 -> 4 bytes), and document that only one ESP32 may transmit drive commands at a time (unplug the stick when using the bridge; put the bridge in listen when using the stick).
2026-10-02 Relay overheard drive commands from the bridge as CMD lines
    The bridge already hears the stick's DrivePacket broadcasts on the shared ESP-NOW
    channel but threw them away. Print them as "CMD <left> <right>" and parse them in
    bridge.py so a recorder can log what the human commanded alongside the telemetry.
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2026-10-02 MCP server: recording, line_view, and autonomous line following
    Covers the telemetry recording feature (Recorder, start/stop_recording, add_marker,
    take_photo, auto-photo) and analyze_csv.py fixes that were already in the working tree,
    plus: video and stick-command capture (video.mp4, video_times.csv, commands.csv),
    line_view(), and start_line_follow / line_follow_status. One confirmed_safe covers a run;
    it stops by itself on finish, lost line, stale camera or telemetry, timeout, or stop().
    [analyze_csv.py, recording.py, robot_server.py]
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2026-10-02 Add manual and line-follow run recordings (no video)
    Telemetry CSVs, stick commands, per-frame follow logs, detections and photos for the manual
    tape runs and follow_run1-4. Videos are ignored (*.mp4) and stay local.
    [bench_follow1.csv, commands.csv, detections.csv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]
2026-10-02 MCP server: turn_to_me (spin in place to face a person) with person_view
    YOLO pose finds the person in the live camera stream; a controller turns a
    bearing into a world-frame yaw target and spins closed-loop on IMU yaw. Holds
    and re-aims as the person moves, learns a per-direction stall bump, and
    refuses to start with 0 or >1 people in view. max_seconds, lost_timeout_s and
    spin_speed_dps are settable at start and live via turn_to_me_set.
    [person_track.py, person_track_sim.py, person_vision.py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]
2026-10-02 Add turn_to_me run recordings (no video)
    [commands.csv, turn_log.csv, turn_to_me_run1.csv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]
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2026-10-02 Add phone-display line-follow run recordings (no video)
    [commands.csv, follow_log.csv, follow_phone_display_run1.csv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]
2026-10-03 Bring-your-own battery: three options, remove dock, split battery BOM
    - Add context-pack/05-battery-options.md (12 V SLA, 18 V tool pack, 12 V LiFePO4)
    - Add context-pack/battery_bom.csv with a 2026-10-03 price snapshot
    - Remove batteries, charger and F1 terminals from bom.csv (total $237.70)
    - Delete 05-docking.md and all dock references
    - Rewrite README, manual, overview, physical design and drivetrain/power docs
    [battery_bom.csv, bom.csv]
2026-10-03 Line follow: AI-in-the-loop controller, line_follow_report, runbook
    Follower stops with a claim (stale/lost/finish_candidate/end_of_tape) instead
    of trying to be right; line_follow_report returns the last frames plus a
    fresh still so the AI can judge. Separate forward/turn limits, spin breakaway
    floor and stall boost, ignore_finish_s for resuming past false finishes,
    camera warmup. LINE_FOLLOW_RUNBOOK.md has the stop->look->verdict->recover
    procedure and lessons from the full runs.
    [camera_stream.py, line_follow.py, line_follow_sim.py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]
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2026-10-03 Add line-follow run recordings from 2026-10-03 (no video)
    CSV logs only (telemetry, follow_log, commands, video_times); *.mp4 stays
    ignored. Includes follow_post_run1/2, the runs behind the post video.
    [commands.csv, follow_20261003_115628.csv, follow_20261003_115904.csv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]
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2026-10-12 Remove line-following and turn-to-me; add save_photo, doorway policy, peak tilt
    Removed the line-following and person-tracking ("turn to me") experiments from the
    MCP server and repo (code, run logs, post tooling, phone display/bench). They are
    recoverable from the git tag before-experiment-removal; run videos and pose models
    are in ~/ellama_experiments_archive/ (never in git).
    MCP server
    - save_photo: full-res photo saved to recordings/photos/ with a .json sidecar (robot
    pose, brightness, moved_during_capture); optional preview and browser open.
    - look()/photo fetch: returns a real photo or a clear error, never a stream frame; the
    phone address is cached in ~/.cache/ellama/camera_url t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
2026-10-12 MCP server: add phone_status and torch tools
    phone_status reads the phone camera app's /info.json for battery percent and
    torch state (low_battery at or below 20%). torch(on) switches the phone's
    flashlight and reads the state back, reporting a mismatch as an error. Both
    are read-only for the robot and need no confirmed_safe. Tests use a faked
    phone endpoint.
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2026-10-22 Update firmware README for the SensorPacket conversion
    The README still described the retired length-based packet scheme, listed a
    sketch that no longer exists, and gave the encoders' old pins.
    State the no-libraries rule as it is actually meant: nothing beyond esp_now.h
    for robot/controller/bridge communication, while a driver library for reading a
    sensor is fine. The VL53L0X needs one; the AS5600 and MPU6050 do not and still
    use only Wire.h.
    Also document LlamaSensors and the symlink that makes <LlamaSensors.h> resolve,
    the two new ToF sketches, that robot_imu_icm20945 is the last sender still on
    the legacy packet, the C3's CDCOnBoot=cdc requirement, and checking a board's
    MAC before fla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
2026-10-24 Undo the split: the AI work comes back into this repo
    Reverses the Oct 19 refocus. mcp_server, teleop, phone, DRIVING_POLICY,
    .mcp.json and the characterization sweeps (in tools/ now, where the
    find_tags import expects them) return to the paths they had before, so
    their history reconnects rather than ending at a deletion. The droid
    repo's one commit of work since the split -- the named sensor registry,
    range sensing, switchable guards and honest drive feedback -- comes with
    them.
    The submodule seam is gone: robot_server.py imports calibration/bridge.py
    from a REPO_ROOT beside it instead of from an ellama/ checkout, so
    ELLAMA_PATH and the "no eLlama checkout, run git submodule update" exit
    b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
2026-10-24 Remove the motion guard
    motion_guard.py and its stall / encoder_fault / slip / bump detectors go,
    along with everything that fed or read them: the MOTION singleton, the
    on_command / on_enc / on_imu calls in the serial pump and send_drive, the
    motion branch of _drive_refusal and _tilt_gate, the motion half of
    _guard_info and read_telemetry, and ELLAMA_MOTION_GUARD in .mcp.json,
    ollama_bridge and simple_bridge.
    clear_motion_fault is gone as a tool. set_guard keeps only the tilt
    guard: name is now a one-value Literal and the nine motion-only
    parameters (stall, direction, slip, bump, their thresholds and
    encoders_required) are deleted, so the schema no longer advertises
    detectors that do not ex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
2026-10-24 One phone, address given at runtime, lens chosen per call
    The camera is no longer something this server goes looking for. Gone:
    the /24 port scan (_discover_camera, _probe, _local_ip, _read_jpeg,
    CAM_PORTS), the ~/.cache/ellama/camera_url memory between runs
    (_saved_camera, _save_camera) and the rediscover-and-retry path that
    every camera call carried. An address that is wrong is now an error that
    says so, instead of a 10-30 s search that also seemed to wedge the
    phone's own server.
    set_camera("192.168.0.54") supplies it while the server runs, filling in
    https and port 4444; ELLAMA_CAM_URL still does it at startup. set_camera
    reads the app's info endpoint before accepting and keeps the prev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
2026-11-05 Fix what the module split left behind
    Code review of 7e1da04 against the pre-split original. Two real defects:
    admin_tools.py never imported tilt_guard -- the import stayed in
    robot_server.py -- so set_level_reference() raised NameError instead of
    returning, for any call with a live IMU. That is the only way to re-level the
    tilt guard after remounting the IMU or connecting on a ramp.
    drive_tools.register() wrapped only the copy handed to mcp.tool(), so
    robot_server's re-exports and the sweep scripts in tools/ got the unguarded
    functions. Before the split the stacked decorators made the module attribute
    the guarded one. A guard trip mid-move propagated GuardFault instead of
    returning {"ok":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
